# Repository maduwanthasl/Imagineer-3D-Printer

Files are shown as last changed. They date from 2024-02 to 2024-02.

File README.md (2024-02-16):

# Imagineer-3D-Printer 📝

🛠️ Crafted with passion and precision, my DIY 3D printer, 'Imagineer,' is the culmination of two weeks of dedicated hands-on work. This GitHub repository serves as a comprehensive archive of the entire journey, offering a wealth of resources including design files, step-by-step assembly instructions, troubleshooting tips, and firmware customization guides. Beyond just a project, Imagineer embodies a community-driven ethos, inviting makers from all backgrounds to contribute, collaborate, and innovate together. Join us in shaping the future of personalized 3D printing! 🚀🖨️ #DIY #3DPrinting #OpenSource

imagineer 3D printer

## Introduction:
- Imagineer: An innovative DIY project for crafting my own 3D printer.
- Core components: Stepper motors, microcontroller, extruder, and frame, powered by standard electrical outlets.
- Primary goal: Empowering makers to fabricate customized 3D objects with precision and creativity.
- Meticulous construction process: Rigorous part selection, prototyping, and iterative refinement for superior print quality.

## Final Outcome:

[final outcome.mp4](https://github.com/maduwanthasl/Imagineer-3D-Printer/assets/107339150/551f6159-dbec-4fbf-8eaf-94cd0e2501cf)

## Building Process

#### Planning and Design Phase
- Initially, I formulated a plan outlining the design and functionality goals for my DIY 3D printer.
- I created sketches and diagrams to visualize the layout and structure of the printer.

#### Component Selection and Acquisition
- I compiled a detailed list of components required for building the 3D printer, considering factors such as performance, compatibility, and cost-effectiveness.
- After finalizing the component list, I proceeded to order the necessary parts from suppliers.
  
#### Frame Construction 
<p align="center">
  
</p>
- Using aluminum extrusion profiles, M5 screws, and M5 T-nuts, I constructed the frame of the 3D printer.
- To reinforce the frame structure, I utilized aluminum corner profiles and corner brackets, ensuring stability and durability.

#### Attaching Motion Components
- I attached motor brackets to two Z-axis stepper motors and an X-axis motor, securing them to the frame.
- Linear rails were installed to support the X-axis motion, along with a hotend holder and other 3D-printed parts for assembly.
  
#### Adding Y-axis Motion
- Similar to the X-axis setup, I attached 8mm short linear bearings to the bed frame and installed them through the linear rail.
- Additionally, I added a Y-axis motor to drive motion along the Y-axis.
  
| pic 3 (1) |  |
|---|---|
| Adding z motors + x axis  | Adding z axis |

#### Assembling Electronic Components
- I installed the extruder motor and TWO TREES Dual Drive BMG Extruder onto the frame, securing them in place.
- The PTFE tube was connected to the extruder assembly to guide filament to the hotend.

#### Wiring
- Electrical wiring was carefully routed and connected to the stepper motors, endstops, extruder, display, thermistor, fans, and other electronic components according to the printer's wiring diagram.
- Each wire was meticulously routed to ensure proper organization and prevent interference with moving parts.
- Connections were secured using appropriate connectors, terminals, or soldering, ensuring reliable electrical connections throughout the printer.
- Before powering on the printer, a thorough inspection of all wiring connections was conducted to verify correctness and safety.
  
|  |  |
|---|---|
| Adding extruder motor + hotend | Wiring diagram |

#### Firmware Installation
- For my DIY 3D printer, I utilized Marlin firmware version 2.1.2.1, which provides extensive customization options and compatibility with various printer configurations.
- Additionally, I explored firmware options from the BigTreeTech family, including SKR main board firmware, to evaluate alternative features and optimizations for my printer setup.
- After selecting the appropriate firmware, I flashed it onto the printer's microcontroller using the recommended flashing tool and procedure.
- As part of personalization, I added a custom boot screen to the firmware, reflecting the unique identity of my Imagineer 3D printer.
- Following firmware installation, I meticulously reviewed and adjusted configuration files to tailor settings to my specific hardware and preferences.
- Comprehensive testing was conducted to ensure proper functionality and compatibility with the printer's components and features.
  
|  | pic 5 (2) |
|---|---|
| Bootscreen | LCD screen |

#### Calibration and Testing
- Following firmware installation, I meticulously reviewed and adjusted configuration files to tailor settings to my specific hardware and preferences.
- Comprehensive testing was conducted to ensure proper functionality and compatibility with the printer's components and features.
- I calibrated the currents of the motor drivers to optimize performance and prevent overheating or skipping steps.
- Temperature calibration of the hotend was performed to ensure accurate and consistent extrusion temperatures for optimal print quality.
- Distance calibration of the X, Y, Z axes, and extruder motor was carried out to fine-tune motion accuracy and alignment.

## Printed parts

| pic 6 (2) | pic 6 (4) |
|---|---|
| pic 6 (3) | pic 6 (1)|
|---|---|

## Bill of Materials - Form local sellers

### 1. Aluminum Extrusion:
| Component | Details | Quantity | Unit Price (Rs) | Total Price (Rs) |
|---|---|---|---|---|
| 4040 Double T Slot Aluminium Extrusion Profile Silver 2m | Length (mm) : 2000mm | 1 | 13,000.00 | 13,000.00 |
| T-Slot 2040 Aluminium Profiles Extrusion Linear Guide For CNC 3D Printers| | 1 | 4,290.00 | 4,290.00 |
| T Slot 2020 Aluminium Extrusion Profile 20 Extrusion Anodized Linear Rail 20mm X20mm 1M | | 2 | 4,580.00 | 9,160.00 |

### 2. Display:
| Component | Details | Quantity | Unit Price (Rs) | Total Price (Rs) |
|---|---|---|---|---|
| BIGTREETECH TFT35 E3 V3.0 Touch Screen Display for 3D Printers  | | 1 | 6,650.00 | 6,650.00 |

### 3. Nuts and Screws:
| Component | Details | Quantity | Unit Price (Rs) | Total Price (Rs) |
|---|---|---|---|---|
| M5 Stainless Steel Hex Socket Head Cap Screw Allen Bolt | Length (mm) : 8mm | 1 | 23.00 | 23.00 |
| M3 Stainless Steel Hex Socket Head Cap Screw Allen Bolt | Length (mm) : 12mm | 45 | 14.50 | 652.50 |
| M3 Black Grade 12.9 Alloy Steel Hex Flat Socket Head Countersunk CSK Screw| Length (mm) : 5mm | 10 | 13.00 | 130.00 |
| M3 Black Grade 12.9 Alloy Steel Hex Flat Socket Head Countersunk CSK Screw| Length (mm) : 10mm | 10 | 14.00 | 140.00 |
| M3 Black Grade 12.9 Alloy Steel Hex Flat Socket Head Countersunk CSK Screw| Length (mm) : 15mm | 10 | 17.50 | 175.00 |
| M3 Stainless Steel Hex Socket Head Cap Screw Allen Bolt | Length (mm) : 8mm | 12 | 12.50 | 150.00 |
| M5 T Slot Nut for 20 Aluminium Extrusion | | 30 | 38.00 | 1,140.00 |
| M5 Big Corner Angle Bracket for 20 Aluminium Extrusion | | 6 | 140.00 | 840.00 |
| M5 Low Profile Black Grade 12.9 Alloy Steel Hex Socket Screws | Length (mm) : 8mm | 80 | 12.00 | 960.00 |
| M3 Stainless Steel Hex Socket Head Cap Screw Allen Bolt | Length (mm) : 30mm | 31 | 16.50 | 511.50 |
| M5 Low Profile Black Grade 12.9 Alloy Steel Hex Socket Screws | Length (mm) : 25mm | 4 | 19.00 | 76.00 |
| M3 Stainless Steel Hex Socket Head Cap Screw Allen Bolt | Length (mm) : 6mm | 5 | 11.00 | 55.00 |
| M5 Stainless Steel Hex Nut | | 20 | 10.00 | 200.00 |
| M3 Stainless Steel Hex Nut | | 25 | 7.50 | 187.50 |
| M3 Stainless Steel Plain Flat Washer | | 25 | 7.50 | 187.50 |
| M3 M3x4x4.2 Knurled Copper/Brass Insert 10pcs Set | | 1 | 180.00 | 180.00 |

### 4. Miscellaneous:
| Component | Details | Quantity | Unit Price (Rs) | Total Price (Rs) |
|---|---|---|---|---|
| 8mm Short Linear Bearing | LM8UU | 2 | 200.00 | 400.00 |
| TWO TREES Dual Drive BMG Extruder Btech Cloned (Right) Black | | 1 | 3,300.00 | 3,300.00 |
| 24V 15A Power Supply SMPS (Aluminum Cover - with Fan) | | 1 | 5,100.00 | 5,100.00 |
| NSK 625ZZ Deep Groove Ball Bearing 5x16x5mm (Indonesia) | | 1 | 520.00 | 520.00 |
| D14L25 Rigid Shaft Coupling Clamp | Coupling : 5x8mm | 2 | 180.00 | 360.00 |
| 4pcs M4 Medium Hand Twist Bed Leveling Nut Die Mold Spring | (Yellow Blue) Screw Kit | 1 | 600.00 | 600.00 |
| 8mm Linear Shaft Smooth Shaft Rod | Length (mm) : 1000mm | 3 | 1,800.00 | 5,400.00 |
| GT2 20T 20 Teeth 5mm Bore 6mm Width Timing Pulley | Color : Silver | 1 | 180.00 | 180.00 |
| GT2 (Rubber with Fiberglass) 6mm Open Timing Belt 1m | | 4 | 290.00 | 1,160.00 |
| 3D Print Trimming Deburring Knife with 10pcs Blade Kit | | 1 | 2,450.00 | 2,450.00 |
| 8mm 1 Bag (10.5m/Bag) Spiral Wire Wrapping Tube Cable Sleeves | Color : Black | 1 | 400.00 | 400.00 |
| eSUN PLA+ 3D Printer Filament 1.75mm 1kg | Color : White | 1 | 5,500.00 | 5,500.00 |
| 5pcs M3 Small Full Metal Hand Twist Bed Leveling Nut Spring Screw Kit| | 1 | 370.00 | 370.00 |
| MK8 Copper/Brass Nozzle 1.75mm | Size : 0.2mm | 1 | 50.00 | 50.00 |
| MK8 Copper/Brass Nozzle 1.75mm | Size : 0.6mm | 1 | 50.00 | 50.00 |
| 3pins Mini Micro Limit Switch 5A 125~250V 10T85 SPDT Snap Action| | 3 | 225.00 | 675.00 |
| 100K Ohm NTC 3950 Thermistors Temperature Sensor With Cable Dupont Head For Heated Bed 3D Printers| | 1 | 245.00 | 245.00 |

## Bill of Materials -Ali express

#### 1. Joint Board Plate Corner Angle Bracket Connection Joint Strip 90 Degree:
| Component | Details | Quantity | Unit Price (US $) | Total Price (US $) |
|---|---|---|---|---|
| Joint Board Plate Corner Angle Bracket Connection Joint Strip 90 Degree | Color: Silver | 8 | 1.43 | 11.21 |

#### 2. E3D-V6 J-head Hotend 1.75MM Filament 0.4MM:
| Component | Details | Quantity | Unit Price (US $) | Total Price (US $) |
|---|---|---|---|---|
| E3D-V6 J-head Hotend 1.75MM Filament 0.4MM | Long Distance, 24V50W High Power | 1 | 7.74 | 7.74 |

#### 3. DC Cooling FanCentrifugal Blower Fan 12V / 24V:
| Component | Details | Quantity | Unit Price (US $) | Total Price (US $) |
|---|---|---|---|---|
| DC Cooling FanCentrifugal Blower Fan 12V / 24V | Brushless 2-Wire Cooling Fan | 1 | 2.37 | 2.37 |

#### 4. 3D Printer Parts 10A 250V Power Switch AC Power Outlet:
| Component | Details | Quantity | Unit Price (US $) | Total Price (US $) |
|---|---|---|---|---|
| 3D Printer Parts 10A 250V Power Switch AC Power Outlet | With Red Triple Rocker Switch Fused Module Plug | 1 | 2.73 | 2.73 |

#### 5. BIGTREETECH BTT SKR MINI E3 V2 Control Board 32bit:
| Component | Details | Quantity | Unit Price (US $) | Total Price (US $) |
|---|---|---|---|---|
| BIGTREETECH BTT SKR MINI E3 V2 Control Board 32bit | With TMC2209 | 1 | 26.98 | 26.98 |

#### 6. Nema17 17HS4401S 4401 42 stepper motor 1.8° 1.5A 40MM:
| Component | Details | Quantity | Unit Price (US $) | Total Price (US $) |
|---|---|---|---|---|
| Nema17 17HS4401S 4401 42 stepper motor 1.8° 1.5A 40MM | 17HS4401, 5PCS | 1 | 45.58 | 45.58 |

## Parts requied for 3d printer
 - [X-axis](https://github.com/maduwanthasl/Imagineer-3D-Printer/tree/main/3D%20printed%20parts/x%20axis)
 - [Y-axis](https://github.com/maduwanthasl/Imagineer-3D-Printer/tree/main/3D%20printed%20parts/y%20axiz)
 - [Z-axis](https://github.com/maduwanthasl/Imagineer-3D-Printer/tree/main/3D%20printed%20parts/z_axis)
 - [Other parts](https://github.com/maduwanthasl/Imagineer-3D-Printer/tree/main/3D%20printed%20parts)

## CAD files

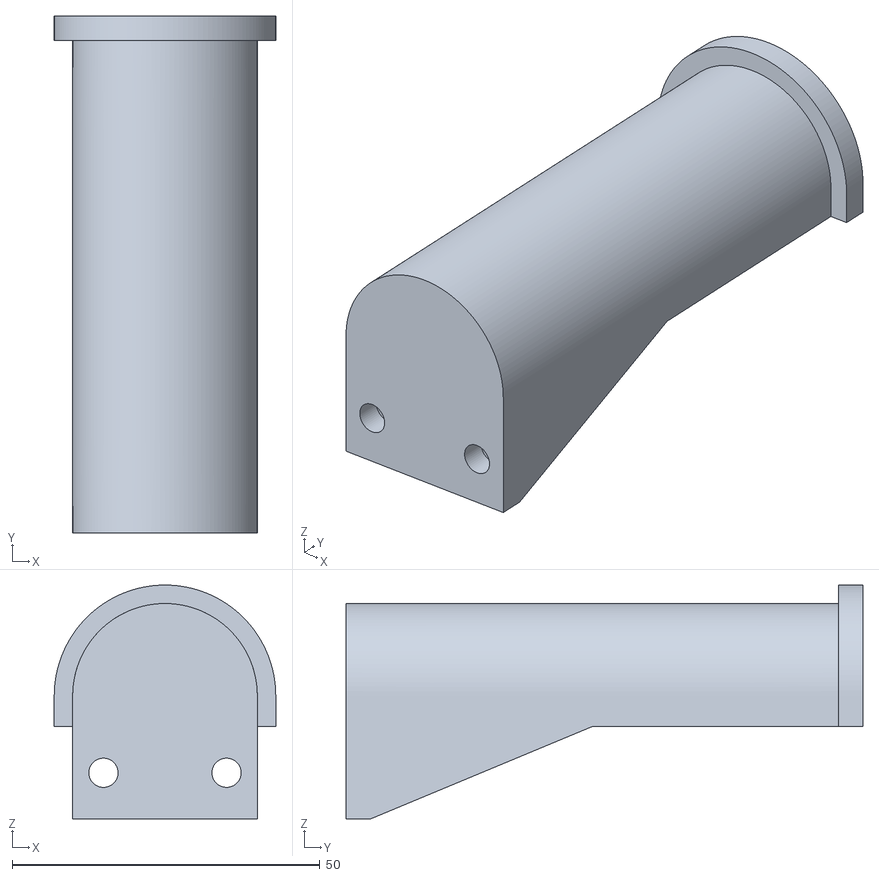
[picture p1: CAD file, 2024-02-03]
3D printed parts/C201_-_Spool_mount (1).stl
36.0 x 84.0 x 38.0

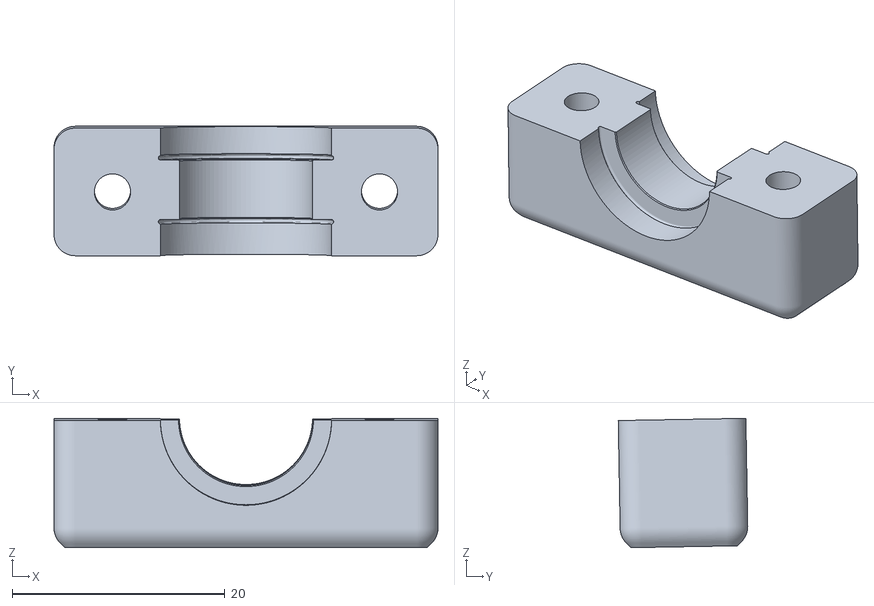
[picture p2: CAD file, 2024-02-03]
3D printed parts/x axis/E3D_V6_Clamp.STL
36.1 x 12.2 x 12.2

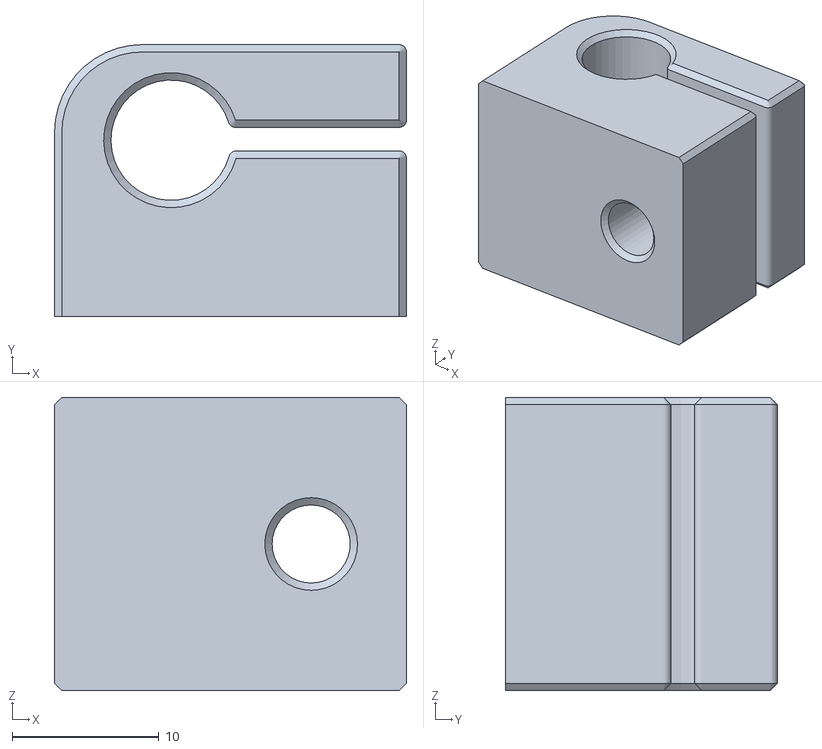
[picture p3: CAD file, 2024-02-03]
3D printed parts/y axiz/support_rod_8mm______________4.STL
24.0 x 18.5 x 20.0

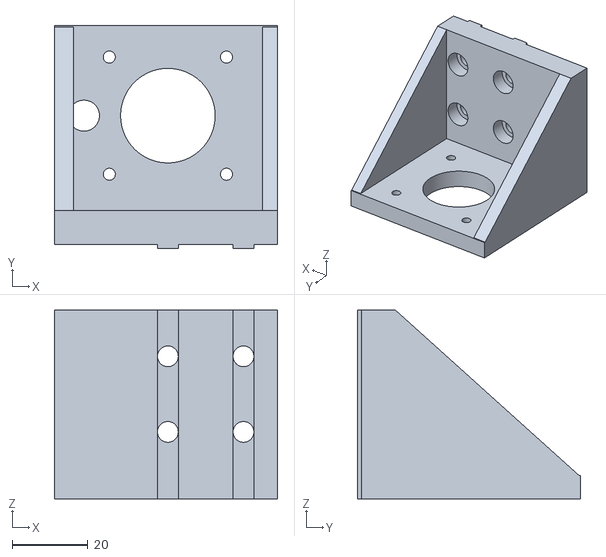
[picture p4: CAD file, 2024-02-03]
3D printed parts/z_axis/1_Z_Motor_Mount_Left.stl
59.0 x 59.0 x 50.0

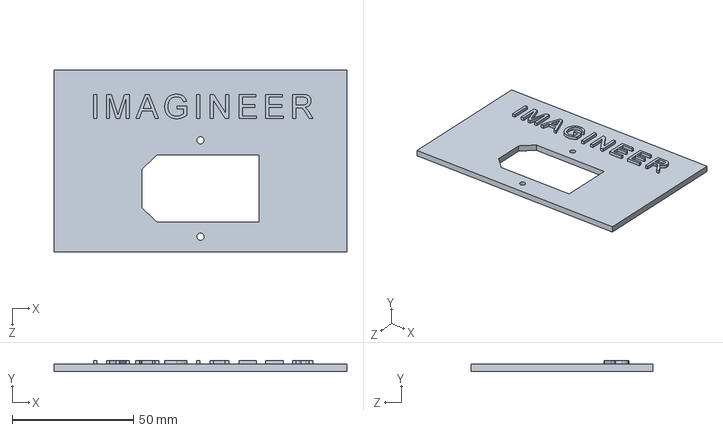
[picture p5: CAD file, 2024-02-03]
3D printed parts/power_Supply_box_cover.SLDPRT
121.0 x 4.50 x 75.0 mm

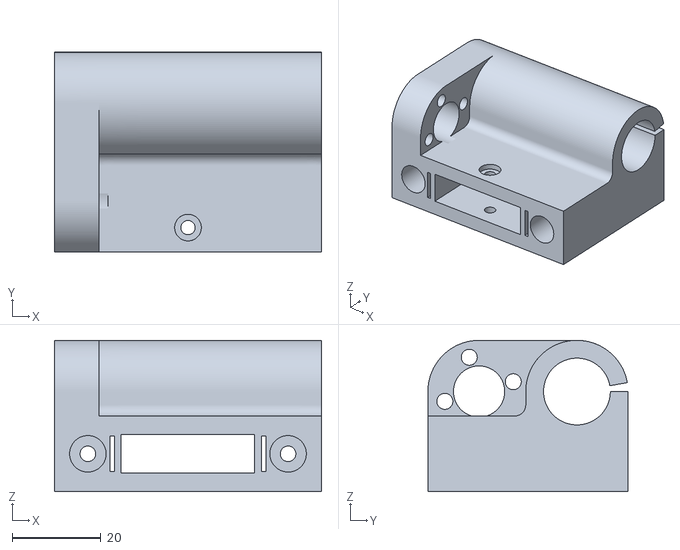
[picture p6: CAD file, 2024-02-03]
3D printed parts/x axis/X_Idler_Right_V1.1_Leo_N.stl
60.0 x 45.0 x 34.0

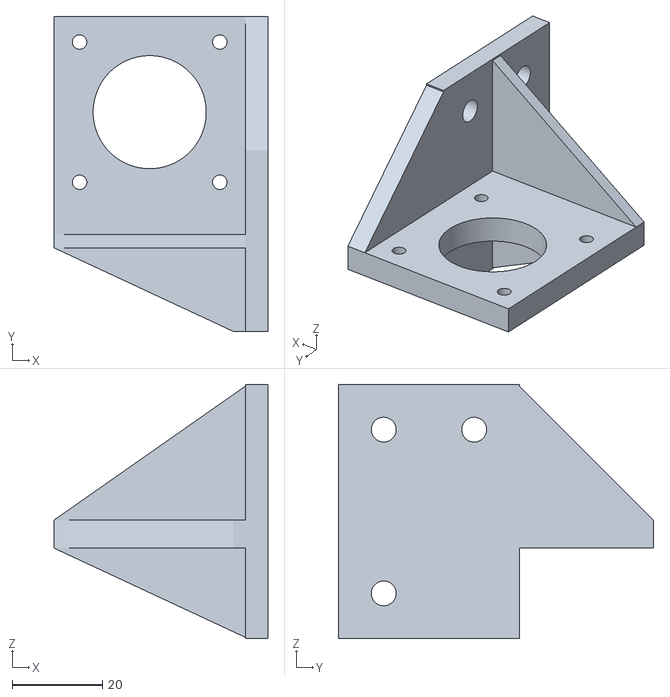
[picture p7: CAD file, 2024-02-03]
3D printed parts/y axiz/1_Y_Motor_Mount.stl
47.3 x 69.6 x 56.2

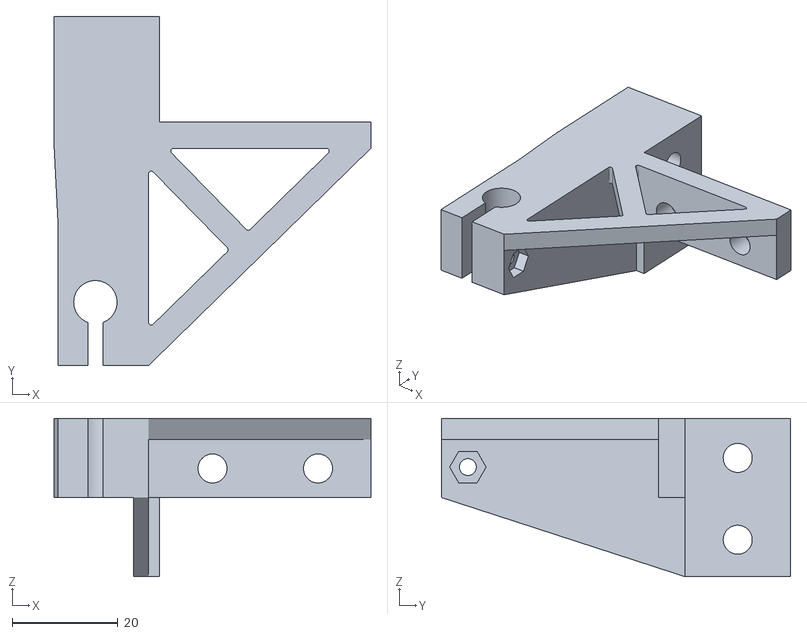
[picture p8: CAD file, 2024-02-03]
3D printed parts/z_axis/1_Z_Rod_Holder_Left.stl
60.0 x 66.1 x 30.0

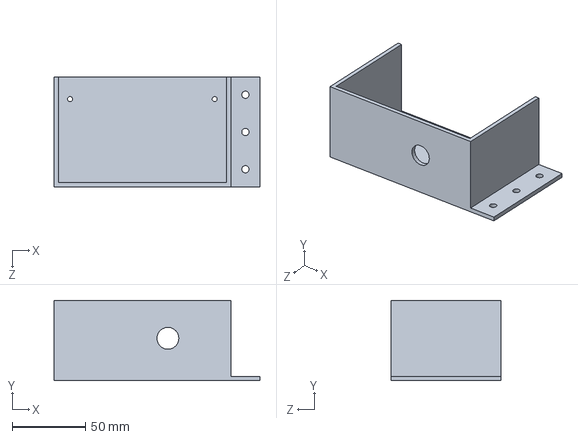
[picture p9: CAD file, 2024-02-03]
3D printed parts/power_Supply_box.SLDPRT
141.0 x 55.0 x 75.0 mm

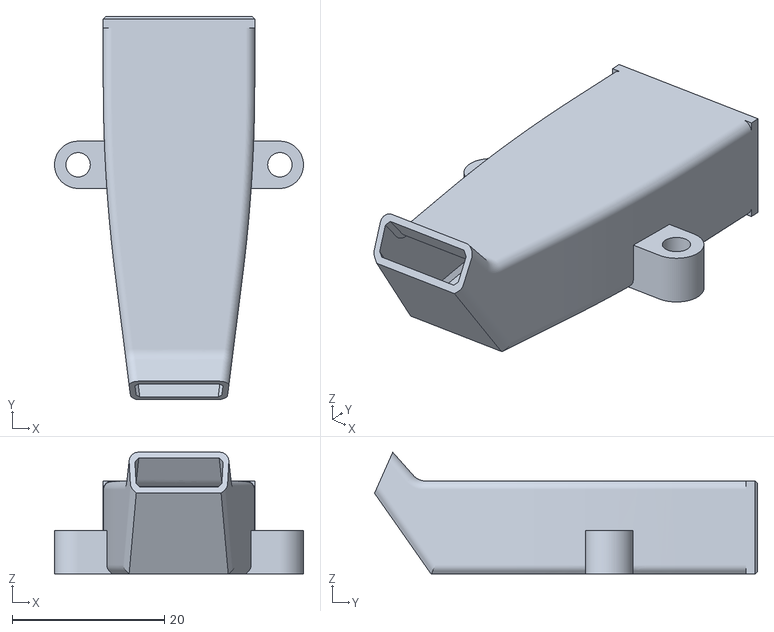
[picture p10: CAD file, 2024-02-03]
3D printed parts/x axis/V6_Fan_Duct.STL
32.7 x 50.3 x 16.0

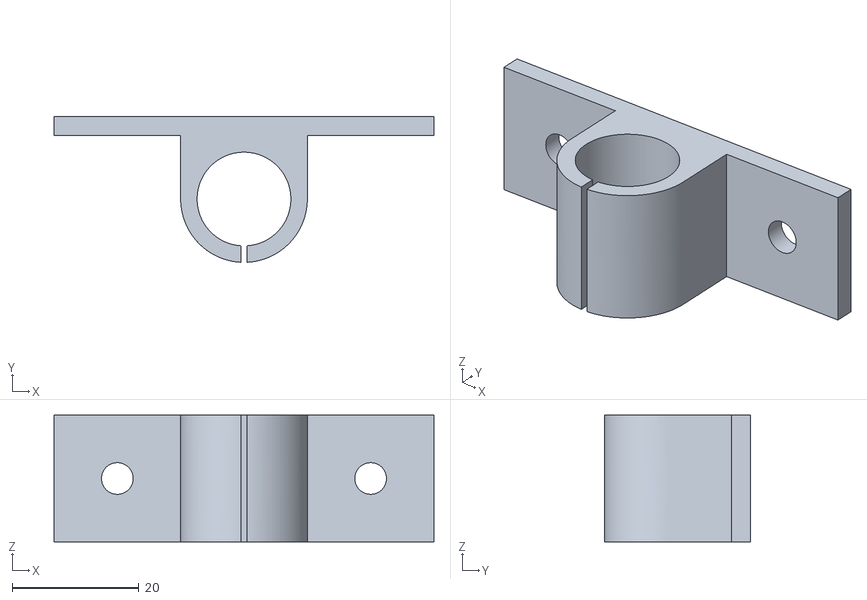
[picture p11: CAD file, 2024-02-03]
3D printed parts/y axiz/C201_-_2020_Print_Bed_Linear_Bearing_Style_3______________4.stl
60.0 x 23.0 x 20.0

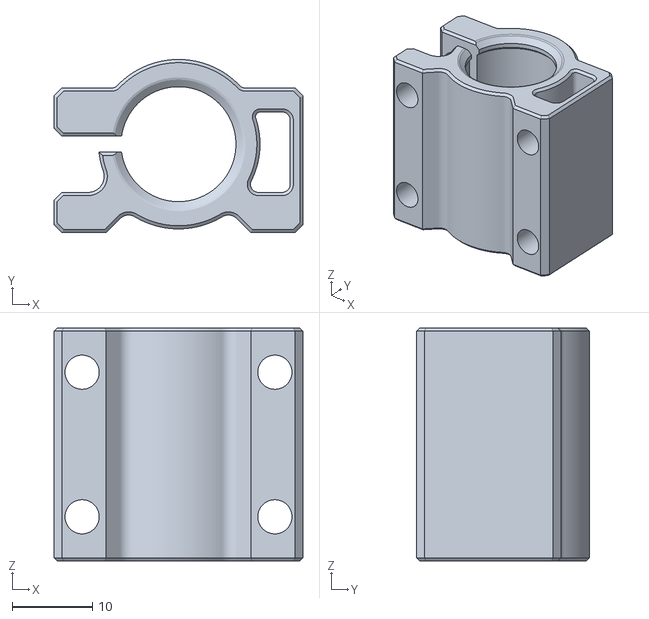
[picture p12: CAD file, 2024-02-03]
3D printed parts/x axis/sc8uu-igus-drylin_v3_________________3.stl
31.0 x 21.5 x 29.0

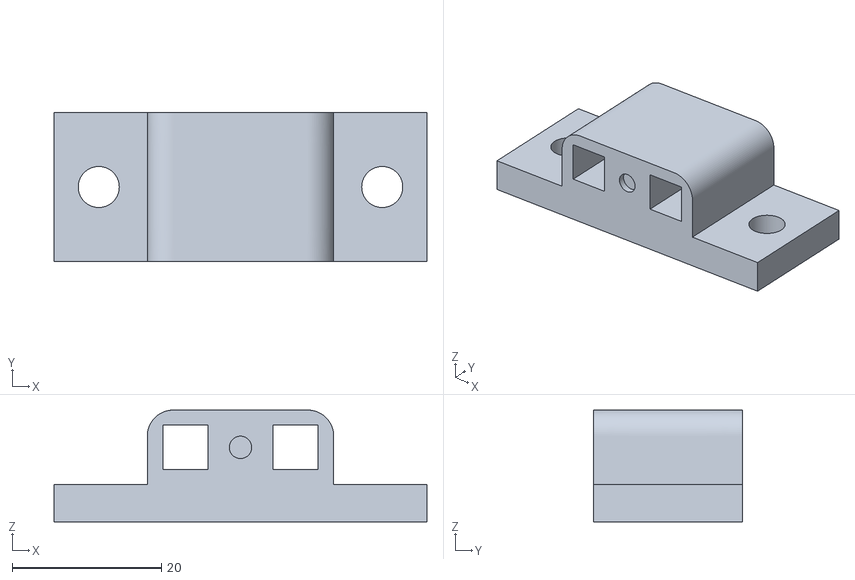
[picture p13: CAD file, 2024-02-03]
3D printed parts/y axiz/1_Y_Belt_Block.stl
50.0 x 20.0 x 15.0

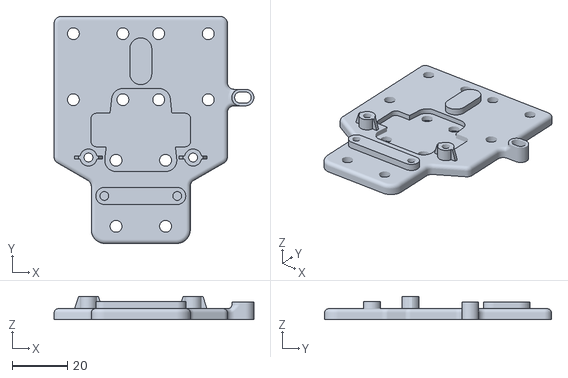
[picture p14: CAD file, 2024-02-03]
3D printed parts/x axis/X_Carriage.STL
72.6 x 82.5 x 8.50

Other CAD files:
3D printed parts/z_axis/1_Z_Motor_Mount_Right.stl
3D printed parts/z_axis/1_Z_Rod_Holder_Right.stl
3D printed parts/y axiz/1_Y_Belt_Tensioner.stl
3D printed parts/x axis/E3D_V6_Mount.STL
3D printed parts/power_Supply_box.STL
3D printed parts/power_Supply_box_cover.STL
3D printed parts/x axis/X_Idler_Left_V1.1_Leo_N.stl
3D printed parts/x axis/X_Idler_Right_Tensioner-11.4_Leo_N.stl
3D printed parts/y axiz/C201_-_Y_Endstop_________________2.stl

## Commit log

2024-02-03 Bootscreen
    I have added a custom animated boot screen by using Windows Paint to create frame_x.bmp files. To generate the bitmap, I utilized the website "https://marlinfw.org/tools/u8glib/converter.html".
    In this section, I have added frame time periods.
    "
    #ifdef CUSTOM_BOOTSCREEN_ANIMATED_FRAME_TIME
    // Each frame has its own custom duration
    const boot_frame_t custom_bootscreen_animation[] PROGMEM = {
    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
2024-02-03 3D printed parts
    Here I used some 3d printed parts.
    [1_Y_Belt_Block.stl, 1_Y_Belt_Tensioner.stl, 1_Y_Motor_Mount.stl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]
2024-02-15 Create Marlin confutation files
